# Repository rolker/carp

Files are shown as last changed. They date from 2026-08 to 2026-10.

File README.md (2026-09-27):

# CARP — Cheap-Ass ROV Project

A low-cost, ROS 2–capable inspection ROV for relocating and imaging sidescan
sonar contacts in shallow water, deployed from a kayak.

## Mission

CARP is a long-daydreamed ROV build with a concrete first job. Sidescan and
bathymetry surveys produce contacts faster than anyone can dive them; CARP is
a cheap camera platform for closing that loop: drop on a contact, find it,
image it, and log the result against the sonar record.

That job drives the v1 design but isn't the only goal — the envelope below
describes the first site, not the vehicle's ambitions. Deeper sites are
expected later (see ADR-001).

**Operating envelope**

| Parameter | Value |
|---|---|
| Design depth (v1, first site) | 5 m |
| Expected visibility | ~3 m |
| Working radius | ~15 m from downline |
| Deployment | Kayak, tethered |
| Water | Freshwater primary; saltwater capable |
| Cost | ~$2,000 as built (the "$500 build" did not survive contact with procurement — see `docs/bom.md`) |

## Design posture

Current leanings from an early design brainstorm, not final commitments —
`docs/decisions.md` grades each record by how committed it actually is.

- **Tethered, not autonomous.** The tether is not a limitation to be removed —
  it carries Ethernet, enables one-way acoustic ranging, and is the recovery
  path. See `docs/decisions.md` ADR-009.
- **Relocation is the hard problem, not the vehicle.** With 3 m visibility you
  can sit on top of a target and not see it. The downline is the primary
  navigation aid.
- **ArduSub for control, ROS 2 for payload.** Pixhawk owns the control loop;
  the Pi owns cameras, logging, and future DSP.
- **Project11 interfaces where they transfer**, not the full autonomy stack.
  See ADR-010.

## Repository layout

```
docs/
  decisions.md          Architecture decision records
  bom.md                Bill of materials, ordered vs pending
  power-budget.md       Load analysis, battery sizing, wiring gauge
  wiring.md             Power tree, signal map, grounding rules
  frame-and-mixing.md   ArduSub motor matrices, verified from source
  housing-layout.md     Tube diameter, dome fit, endcaps, frame geometry, CAD variables
  sled.md               Camera mount, slide-out sled, stereo test plan
  bringup-checklist.md  Bench acceptance tests before anything is sealed
  field-checklist.md    Dive-day card: night-before, launch, in-water, after
  navigation.md         Downline method, scaling lasers, acoustic ranging
  open-questions.md     Unresolved decisions
  prior-art.md          Survey of other cheap ROV builds, distilled lessons
params/
  ArduSub parameter files
```

## Status

Pre-build. Everything ordered has arrived (inventoried 2026-09-26) — Phase 1/2
acceptance testing still to do. The topside dry box came too small and needs
replacing.
Mechanical design open. Print shop online as of 2026-08-30 (Onshape →
Centauri Carbon 2, validated on a Pi 5 bench holder).

## License

TBD

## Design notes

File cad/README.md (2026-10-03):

# CAD

> **Decided vs proposed:** most of this file is agent proposals from design
> discussion, not approved decisions. `docs/open-questions.md` lists which
> is which — check it before treating anything here as settled.

Onshape is the CAD tool; the Centauri Carbon 2 prints the parts. This file
is the working plan for turning `docs/sled.md` and `docs/housing-layout.md`
into a printable stereo camera carrier. Trim it as the steps get done.

- `vendor/` — manufacturer STEP files (git-ignored) and where to get them
- `reference/` — vendor drawings (Pi 5 mechanical)
- `prints/` — STLs of parts actually printed, so a print traces back to a design
  (`pi_bracket.stl`: the 2026-08-30 Pi 5 bench holder, Onshape practice part,
  in daily bench use. Its two pins beside the corner pins, at (3.5, 9.5) and
  (61.5, 46.5), sit in the Pi 5's **Active Cooler mounting holes** — cut them
  off or reprint without them before fitting the cooler, and keep the space
  under those holes clear for the cooler's push-pin tips;
  `coupon_a_c1.stl` and `coupon_b1.stl`: the 2026-09-28 tolerance
  coupons, §4)
- `onshape-notes.md` — Onshape plans, API limits, AI/MCP options and 2026
  changes, for agents (researched 2026-09-27)

**Onshape document:** `carp` (folder `carp`) —
<https://cad.onshape.com/documents/ec758b3ca6b65519093ac0d1>

## Next bench print: Pi holder + stereo bar in one piece

The Pi holder has to be reprinted without the cooler-hole pins anyway, so
the next iteration combines it with a stereo camera bar (both cameras at
`stereo_baseline` on standoffs, stock 150 mm cables to the Pi) as one bench
print — the stage-1 air test rig.

- **Use an Assembly to check fit, a Part Studio to make the print.** An
  assembly exported to STL is several overlapping solids again. For one
  printed piece, bring the holder into the camera bar's Part Studio with a
  *Derived* feature (or rebuild it there) and join them with *Boolean →
  Union*, so the export is a single solid.
- Drop the two cooler-hole pins; keep the four corner pins.
- **Print-only camera seats: slide-in rails** (`docs/sled.md`, "Holding each
  board"), chosen 2026-10-02 from the coupons (§4). Groove height from
  coupon A.

## First target: camera carrier + stand-in plate

Not the sled yet. The first print is **stage 1 of the test plan in
`docs/sled.md`**: the camera carrier and a printed stand-in for the front
lid. Small, needs no housing, and it tests the part that matters most.
Model it so it grows into the real front lid and sled without a restart.

## 1. Measure first

Calipers, ~20 minutes. These decide the geometry. Fill in the values here,
then carry them into the docs (the way the 71.9 flange went into
`housing-layout.md`).

| Measurement | Value (mm) | Notes |
|---|---|---|
| Dome height `H`, flange back face → apex | 26.7 ± 0.2 | Straightedge bridged across both domes (2026-09-27): rule on edge 46.1 − 19.6 = 26.5; rule flat 27.6 − 0.7 = 26.9 |
| Dome glass OD `2R` | 52.4 | Taken 1 mm above the flange front face (2026-09-27); glass narrows right away, no cylindrical skirt |
| Dome glass ID at the flange | 47.25 | Measured 2026-09-27 from the back. Wall (52.4 − 47.25) / 2 ≈ 2.6 |
| Dome flange thickness | 2.0 | Measured 2026-09-27. The listed 3/8" flange is the radial width: (71.9 − 52.4) / 2 = 9.75 |
| B0444 board width × height | 25.1 × 24.4 | Measured 2026-09-27. STEP says 25 × ~24 |
| B0444 hole pattern | 21.05 × 12.55, Ø≈2.0 | 2026-09-27, caliper spans (outer / inner): 21-dir 23.1 / 19.0 → 21.05, Ø 2.05; 12.5-dir 14.5 / 10.6 → 12.55, Ø 1.95. Matches STEP (21 × 12.5). Two earlier 12.5-dir readings (14.7 / 11.55, 14.55 / 11.5) gave ~13.1 but an impossible Ø ~1.55 — bad inner span, discarded. STEP lists Ø2.2 |
| B0444 lens front above board front face | 17.0 | 2026-09-27, at current focus: lens front → PCB back 18.7 − PCB 1.7. STEP says ~16; changes with focus |
| B0444 lens barrel OD | 14.0 | Measured 2026-09-27. STEP says ~14 |
| B0444 back-side component height | 2.2 | Measured 2026-09-27. STEP says ~2 |
| B0444 connector + ribbon stub past board edge | 8 (design) | 2026-09-27: 12.5 with a loose bend; can be bent to the STEP's ~8. Design to 8 and have the carrier hold the bend (clamp behind the connector) so the ribbon cannot pull on the latch |
| B0444 front-face edge clearance | ≥ 1 clear | 2026-10-02: nothing within 1 mm of the slid edges on the lens side — the rail lips (1.0 overlap) clear |
| B0444 connector height | 2.3 proud of the back face | 2026-10-02. On the back (opposite the lens); the tallest back-side part, so it sets the 2.2 → 2.3 clearance. Ribbon leaves parallel to the board, straight out past the edge |
| Stock camera cable reach | ~100 | 2026-10-02: usable distance from Pi 5 camera connector to board connector on the ~150 mm stock cables, allowing for the bends. Sets where the stereo bar sits relative to the Pi holder |
| Active Cooler push-pin tips below the Pi board | 3.5 | 2026-10-02, measured before fitting. The holder must leave this clear under the two cooler holes |

**Dome centre (from the rows above):** sagitta from the OD point (3.0 above
the flange back face): h = 26.7 − 3.0 = 23.7, r = 26.2, so
R = (h² + r²) / 2h = **26.3** — a hemisphere, to measuring accuracy. The
centre of curvature sits **H − R ≈ 0.4 in front of the flange back face**,
i.e. on the lid's outer face (plus any gasket under the flange). The 2 mm
flange cannot clip the 141° cone: the edge ray (70.5°) leaves the glass
~8.8 above the centre, well clear of the flange top at ~1.6.

- [x] **Sensor row direction:** photograph a horizontal edge with the
      connector down. Do the pixel rows run along the 25 mm side? Result:
      **yes** — rows run parallel to the connector edge (a 25 mm edge; the
      24.4 direction runs connector → far edge). Inferred, not photographed:
      cables-up boards gave upright 1920-wide landscape frames with no
      rotation or flips anywhere in the chain (orientation checks below).
      Connector-down is the same axes rotated 180°.

### Image orientation — which way up is upright?

The bench tests ran with the boards' printing upside down and the cables
up, and the images looked upright. Nothing in this repo rotates or flips
(launch file, patches, scripts checked 2026-09-27), so one of:

1. **The sensor is upright that way** — the board's natural orientation is
   connector-up.
2. **libcamera corrected it** — the overlay declares a `rotation`, and
   camera_ros's default orientation makes libcamera compensate using the
   sensor's own flip bits (no CPU cost, but it reverses the row readout
   order).
3. **The viewing step flipped it** — an ffmpeg/Python preview in the test
   session, not the bag itself.

Checks, on the Pi:

```bash
# 1. Does the overlay declare a rotation? (big-endian u32: 0 or 180)
xxd /proc/device-tree/axi/pcie@120000/rp1/i2c@88000/arducam_pivariety@c/rotation

# 2. With cameras.launch.py running: are the sensor flip bits set?
for d in /dev/v4l-subdev*; do echo $d; v4l2-ctl -d $d --list-ctrls | grep -i flip; done

# 3. Ground truth: cables up, camera pointed at a sheet with "TOP ↑" on it,
#    view a frame decoded straight from the bag in a stock viewer.
```

| Result | Meaning |
|---|---|
| No rotation property, flips off | 1 — cables-up is upright |
| Rotation 180, flips on | 2 — libcamera corrects for a connector-down board |
| Bag frame upside down | 3 — the preview was flipped after the fact |

- [x] Rotation property: **0** (both; `orientation` 2 = external) — Flip
      bits while streaming: **H 0, V 0** (both; camera_ros `orientation` 0)
      — Bag frame upright?: **yes** (2026-09-26 frames decoded with plain
      ffmpeg, and raw-Bayer previews written in sensor row order, both
      upright with the boards cables-up). **Result 1: cables-up is the
      sensor's natural upright.** A "TOP ↑" sheet shot would confirm
      directly.

**For the carrier:** any orientation works as long as both boards are
mounted the same way and both cameras run identical settings — that keeps
the readout order matched for the sync. Pick cables-up or cables-down for
ribbon routing to the Pi, then make the software match (camera_ros
`orientation`) rather than bending the mount to suit. **Calibrate with the
final orientation settings** — changing them afterwards invalidates the
intrinsics. Update the "connector down" assumption above, and `sled.md`,
once decided.

## 2. Onshape document structure

One document, `CARP`:

| Tab | Contents |
|---|---|
| **Variable Studio** `Housing` | Driving variables (list below) |
| **Part Studio** `B0444` | Imported STEP from `vendor/` |
| **Part Studio** `Dome` | Simple model from the measurements: 2.0 flange disc + R 26.3 hemisphere, centre ~0.4 in front of the flange back face, marked as a mate connector |
| **Part Studio** `Front` | Multi-part: layout sketch, lid, carrier, spacers, stand-in plate |
| **Assembly** `Front check` | Two cameras + two domes placed on the parts; clearances and axis alignment |

**`Front` is one multi-part Part Studio** — the Onshape idiom for parts
designed around each other. Lid, carrier and stand-in all reference one
layout sketch, so changing `stereo_baseline` moves everything together, and the
drilling jig comes later from the same sketch.

**Coordinates:** origin at the **front pipe end, on the tube axis** (= the front
lid's inner face; `housing-layout.md`, "Coordinate frame"), +X
forward along the optical axes (vehicle X), **Y to port**, Z up —
right-handed, ROS REP-103, same as `housing-layout.md`, so this drops into a
vehicle assembly (and a URDF export) later.

### Variable naming conventions

Settled 2026-09-27, before the Variable Studio existed — renaming later does
not update expressions that already use a name.

1. **snake_case, whole words, subject first:** `dome_flange_diameter`, not
   `flangeOD`. Names group by part (`camera_*`, `dome_*`, `lid_*`, `tube_*`)
   and match the ROS side of the repo.
2. **Property words:** `diameter`, `radius`, `thickness`, `width`, `height`,
   `length`, `depth`, `spacing` (centre to centre), `offset`, `gap`,
   `clearance`. The only abbreviations are `min` and `max` (and `cg`).
   Say what is meant: `camera_hole_spacing_x`, not `camera_hole_x`.
3. **Axes as a final `_x` / `_y` / `_z`** — vehicle frame (X forward, Y port, Z up)
   unless it is plainly a board's own axes.
4. **Derived values are expressions,** not typed numbers:
   `tube_inner_diameter = tube_outer_diameter - 2 * tube_wall_thickness`.
5. **Units always** (`74 mm`), and the **source in the description field**
   ("measured 2026-09-27", "design choice, sled.md", "from coupon").
6. **Shared vs local:** anything used by more than one Part Studio, or named
   in the docs, lives in the `Housing` Variable Studio. One-part dimensions
   (a rib thickness) are local Variable features. A local variable never
   reuses a shared name.
7. **Print fits get their own variables** so coupon results feed straight
   in (e.g. a rail groove width, a pin diameter), separate from the
   measured dimension they fit (`camera_board_thickness`).
8. **This table mirrors the Variable Studio.** Change a value in Onshape →
   update the table in the same commit as the print or measurement.

### Variable Studio contents

| Variable | Value | Source |
|---|---|---|
| `tube_outer_diameter` | 168.3 mm | 6" sched-40 |
| `tube_wall_thickness` | 7.11 mm | 6" sched-40 |
| `tube_inner_diameter` | `tube_outer_diameter - 2 * tube_wall_thickness` → 154.1 mm | Derived |
| `seal_diameter` | `(tube_outer_diameter + tube_inner_diameter) / 2` → 161.2 mm | Derived; O-ring centreline |
| `stereo_baseline` | 74 mm | Minimum; 74–~95 allowed (`sled.md`) — **decision open** |
| `dome_flange_diameter` | 71.9 mm | Measured 2026-09-26 |
| `dome_bolt_circle_diameter` | 64.5 mm | Measured 2026-09-26, 6 holes ~Ø2.0 |
| `dome_flange_gap_min` | 2 mm | Rule: flanges don't touch |
| `lid_thickness` | 19.05 mm | 3/4" acrylic; 9.53 for the aluminium option |
| `lid_width` | 203.2 mm | 8" |
| `tie_rod_circle_diameter` | 184 mm | M6 tie rods at 45° |
| `camera_hole_spacing_x` | 21 mm | B0444 hole pattern, along the board width (measured 21.05) |
| `camera_hole_spacing_y` | 12.5 mm | B0444 hole pattern, along the board height (measured 12.55) |
| `camera_axis_offset` | 1.3 mm | Hole-pattern centre to optical axis, toward the connector |
| `camera_board_width` | 25.1 mm | Measured |
| `camera_board_height` | 24.4 mm | Measured |
| `camera_lens_height` | 17 mm | Board front face to lens front, measured at current focus |
| `camera_hole_diameter` | 2.0 mm | Measured (STEP 2.2) |
| `camera_board_thickness` | 1.7 mm | Measured 2026-09-27 |
| `camera_lens_barrel_diameter` | 14 mm | Measured; retainer holes clear it |
| `camera_back_component_height` | 2.2 mm | Measured; standoffs clear it |
| `camera_connector_reach` | 8 mm | Connector + tightly bent ribbon past the board edge |
| `dome_height` | 26.7 mm | Flange back face → apex, measured 2026-09-27 |
| `dome_radius` | 26.2 mm | Glass OD 52.4 / 2; sagitta gives 26.3 — hemisphere |
| `dome_flange_thickness` | 2.0 mm | Measured |
| `lid_hole_diameter` | 17 mm | Through-hole for the Ø14 barrel; 16–18 |
| `lid_counterbore_diameter` | 52 mm | Counterbore from the inside for board + connector |
| `lid_counterbore_depth` | 8 mm | Board needs 4.5–7.5; rest is tune margin |
| `tube_length` | 400 mm | **Provisional** — bay stack total, `housing-layout.md` |
| `camera_pupil_depth` | 3 mm | Lens front → entrance pupil. **Estimate**; the wet tune corrects it |
| `dome_center_x` | `lid_thickness + dome_height - dome_radius` → ~19.5 mm | Derived: dome centre (and the camera pupils) in front of the origin |
| `sled_tray_top_z` | −55 mm | Tray top below the axis; ≥ −58.6 so the 100-wide pack pair fits the bore |
| `camera_spacer_thickness` | 3 mm | Starting guess; set per camera by the wet tune |
| `camera_standoff_height` | 3 mm | Board standoffs; clear the 2.2 back-side parts |
| `camera_pin_diameter` | 1.8 mm (placeholder) | *If* printed pins win: pin diameter for the Ø2.0 board holes — set from the coupon (1.8 / 1.85 / 1.9) |
| `print_fit_clearance` | 0.2 mm (placeholder) | General sliding-fit allowance per side — set from the coupon |

## 3. Build order inside `Front`

1. **Layout sketch** on the lid's outer-face plane:
   - the two optical axes at ±`stereo_baseline`/2
   - the dome flange circles and their six-hole patterns
   - the pipe bore and pilot-ring circle
   - the tie-rod circle

   Add a constraint that makes the model fail when the flanges collide
   (`dome_flange_gap ≥ 2`).
2. **Lid** at `lid_thickness`, modelled but not printed — the reference the carrier
   mounts to, and later the drawing for the acrylic.
3. **Camera carrier:**
   - two board seats, each hole pattern 1.3 off its axis toward the
     connector
   - **both boards the same way up** — never mirrored (rolling-shutter
     readout has to match for the sync, `sled.md`)
   - ribs across the span between them
   - board seats per the chosen print-only method (`docs/sled.md`)
   - dowel + screw interface on its front face (to the lid)
   - a slot for each ribbon to exit rearward
4. **Spacer** — one part with an Onshape **configuration** table for
   thickness, 2.5 to 6 in 0.5 steps. Export the set as STLs.
5. **Stand-in plate** — just the lid's inner-face interface (dowel and screw
   holes) plus feet to stand on the bench. It doesn't need to be 19 thick
   or 8" square; only the region the carrier bolts to.

## 4. Printing

- **PLA+ for stage 1** — it is bench only (`docs/bom.md` material rule).
  Reprint in PETG before it goes in the vehicle.
- **Print a tolerance coupon first** — cheaper than reprinting the
  carrier; it picks the board-seat method. Modelled 2026-09-28 in two Part
  Studios (layout proposed by an agent, sizes are starting guesses):
  - **`Coupon A`** (PLA+, one part, 110 × 60 × 8.5, plate down, no
    supports; label "C1"):
    - three **rail pairs**: walls 3 wide × 6.5 tall, lips 23.1 apart
      (`camera_board_width - 2 * coupon_lip_width`), grooves 25.4 wide
      (`camera_board_width + 0.3`) with the floor at
      `camera_standoff_height`, groove height 1.7 + 0.1 / 0.2 / 0.3; end
      stop at the back, board slides in connector end last
    - three **pin pads**: Ø4 bosses × 3 on one diagonal of the 21 × 12.5
      hole pattern, pins Ø1.80 / 1.85 / 1.90 × 2.2 (0.5 above a seated
      board)
    - embossed labels 0.4 high
  - **`Coupon B`** (PETG, nine parts, 112 × 35 × 15, no supports,
    0.12 layers for the threads):
    - two **latches**, printed flat so the arm flexes in the bed plane:
      arm 1.0 / 1.4 × 12, hook 0.8 over a 3 ramp, channel 8.2, rigid wall
      2.5; one **catch** block 8 × 8.8 fits both (0.6 arm deflection)
    - three **M6 × 1.0 stud + nut pairs** (Plastic Thread, ISO profile,
      presets Close / Normal / Loose, labelled C / N / L): studs Ø6 × 12
      on 12 × 12 × 3 bases, nuts 10 A/F × 5
  - **Results** (fill in after printing):

    | Test | Result |
    |---|---|
    | Rails +0.1 / +0.2 / +0.3 | 2026-09-28: +0.1 a bit too tight, +0.2 a bit loose. 2026-10-02: +0.1 works well after a few insertions — **use +0.1** |
    | Pins 1.80 / 1.85 / 1.90 | 2026-09-28: all too small, board moves around. 2026-10-02: pins measure ~0.05 under design (1.90 → ~1.85) |
    | Latch 1.0 / 1.4 (20 cycles) | 2026-10-02: both snap in and work, but hold weakly; 1.0 is weaker |
    | Nut C / N / L | 2026-10-02: all thread smoothly, all wobble a little (L most, C least); all hold when snug |
- **Carrier printed seat-side up** (rails stand up from the seat face, as on
  coupon A). Both seats finish on the same top layer, so they come out flat
  and coplanar. 4+ walls, ≥ 40% infill.
- **Hardware not yet bought** (not in `docs/bom.md`):
  - Nothing for the board seats — print-only (M2 × 6–8 screws + inserts
    only as a fallback)
  - M3 or M4 inserts + screws (carrier to plate)
  - 3 mm steel dowel pins
  - a heat-set tip for the soldering iron

## 5. Tying it back to the repo

- Put the Onshape document link at the top of this file, and name Onshape
  versions to match git commits (e.g. "carrier v1 — 8b89fd0") when a part
  is printed.
- Export STLs for parts that were actually printed, so a print traces back
  to a design.
- Measurements go into the docs once taken.

## First test

Cameras on the carrier, stock 150 mm cables to the bench Pi, calibrate in
air with ROS `camera_calibration` in stereo mode. Check:

- the calibrated baseline matches `stereo_baseline`;
- rectified images line up row for row.

Both hold → the carrier is rigid and correctly oriented. A baseline that
drifts between calibration runs means the print is flexing.

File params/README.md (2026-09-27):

# ArduSub Parameters

Parameter files for CARP, one per configuration stage.

## Conventions

- Export from QGroundControl after each verified change
- Commit the *whole* file, not diffs — ArduSub params are order-independent and
  the full snapshot is what gets reflashed
- Name files `carp-<stage>-<date>.params`

## Known non-default values

| Parameter | Value | Why |
|---|---|---|
| `BRD_SAFETY_DEFLT` (was `BRD_SAFETYENABLE` before 4.7) | 0 | No physical switch reachable in a sealed housing (ADR-007) |
| `BARO_EXT_BUS` | *(set to external bus index)* | Defaults to −1 (disabled). Most common cause of "depth sensor not detected" |
| `FRAME_CONFIG` | *(pending frame decision)* | ADR-012 is Open — six thrusters make BlueROV1 a live alternative to SimpleROV-4/5 |
| `LEAK1_PIN` / `FS_LEAK` | *(AUX pin)* / surface | Leak probe auto-surface failsafe (design review M8) |
| `BATT_VOLT_MULT` | *(calibrate)* | Radiolink power modules are known to read low |
| `MOT_n_DIRECTION` | *(as needed)* | Correct thruster rotation here rather than rewiring inside the housing |
| `MAV_GCS_SYSID` (was `SYSID_MYGCS` before 4.7) | 255 | Required for QGC/Cockpit joystick authority; the #1 "no control" cause |
| `SERIAL2_PROTOCOL` / `SERIAL2_BAUD` | 2 / 921 | Only if Pi connects via TELEM2 UART instead of USB |
| `FS_PILOT_INPUT` | *(verify)* | Pilot-input failsafe timing — matters with browser-based control (Cockpit tab focus) |

**Firmware target:** `Pixhawk1-1M` from Sub/stable (genuine FMUv2 is 1 MB;
plain `Pixhawk1` assumes 2 MB and fails to flash). Pin the working `.apj`.
**Flashed and working (2026-09-26): ArduSub 4.7.1, git `dbe79216`**, loaded
as a custom firmware file from QGC 5.1.4 on Windows. **This board has
2 MB of flash** — the 1M build logs `2M flash - use Pixhawk1 firmware` on
every boot — so it now runs the **full `Pixhawk1` build**, same 4.7.1 /
`dbe79216`, reflashed 2026-09-26 (ADR-008). Pin *that* `.apj`:
`firmware.ardupilot.org/Sub/stable/Pixhawk1/ardusub.apj`.
Custom control code note: MAVLink MANUAL_CONTROL z-axis neutral is **500**
(0–1000 scale), unlike x/y/r at ±1000 — z=0 means full descent on arm.

## Not available

`SUB_FRAME_CUSTOM` is an empty case in `AP_Motors6DOF.cpp`. There is no
parameter-driven custom motor matrix — a custom frame requires a firmware fork.

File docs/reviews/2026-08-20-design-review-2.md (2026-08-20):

# CARP Design Review — 2026-08-20 (second pass)

Independent review by a second agent. The first review (`2026-08-20-design-review.md`)
is excellent and most of its findings have already been incorporated into the source docs.
This pass checks whether anything was missed or left unacted-on, and adds new observations.

Findings ranked BLOCKER / MAJOR / MINOR.

---

## What the first review got right that remains solid

The core architecture (ArduSub + Pi over USB/MAVLink), buoyancy math, wiring gauge
analysis, vacuum gate corrected to 15 inHg, acoustic ranging math and
tether-as-sync-path argument, snag protocol rewrite, and the decision to stay tethered
are all sound. `frame-and-mixing.md`, `sidescan-datum.md`, and `prior-art.md` remain
correct as written.

---

## First-review findings that are still open (not yet acted on)

### B2 carry-forward — snag protocol not in the checklist
ADR-009 now has the correct rewrite. `bringup-checklist.md` Phase 5 has no snag drill
or "haul-test from multiple bearings" step. A written procedure that is never practiced
is not a procedure.

### M3 carry-forward — external compass not on any BOM line
The first review calls for a ~$15–30 external I2C compass and MagFit in Phase 3/5.
Neither the BOM pending section nor the bringup checklist has been updated. It will
surface on first water, not in a drawer.

### M4 carry-forward — ADR-017 not written
The first review calls for ADR-017 (Pi software stack decision) before Phase 3. It is
not in `open-questions.md`, not in `decisions.md`, and not in any checklist. It will
get skipped unless explicitly tracked.

### Minor 10 carry-forward — thermal soak duration discrepancy
The first review recommended 45 min sealed soak; `bringup-checklist.md` Phase 3 says
30 min. One of them is wrong.

### Minor 12 carry-forward — no field-day ops checklist
`bringup-checklist.md` covers bench phases only. First dive needs its own card: cell
voltages, vacuum hold check, tether flaked, quick-release confirmed, downline dropped
and clipped, disarm before hands near props. This was flagged and not created.

---

## MAJOR

### MA1. Relief path in the endcap is called for but never specified

ADR-013, `power-budget.md`, and the bringup checklist all say "relief path in
endcap — confirmed." No doc says what it is: a Schrader valve? A burst disk? A
pop-off rated to what pressure? Without a specific part and a test procedure, this is
a checkbox with no method. A swollen 4S pouch in a sealed PVC tube with a vague
"relief path" is still an unresolved hazard.

**Fix (~$5):** one Schrader valve stem in an endcap hole, core in during diving (seals
against water), core removable for bench venting. Same part already called for by the
vacuum test (it is already in the BOM pending section as "Schrader valve stem + core
tool" — confirm it serves both roles and cross-reference in ADR-013).

### MA2. Camera pod / housing layout is the most blocking unresolved mechanical question

The 2" dome cameras are ordered. Camera pods are "a candidate" in `open-questions.md`.
CSI ribbons are not wet-rated and cannot pass a gland — correctly flagged in the first
review (M5) — but no fallback is specified. The main housing endcap cannot carry two
~70 mm flanges on a 4" cap. There is no pod design, no housing diameter decision, and
no frame layout. These three questions are the same problem and must be resolved before
pipe is purchased.

**Fix ($0):** add "lay out camera geometry and housing diameter on paper before buying
any pipe" as a Phase 0 item, immediately after the battery dimensions are measured on
arrival.

### MA3. XT90-S anti-spark resistor is a consumable — not mentioned anywhere

The pre-charge resistor in the XT90-S male pin is rated for a finite number of
insertions (typically 30–50) before it degrades and the connector becomes a plain XT90.
Field operations mean connecting and disconnecting every dive. There is no mention of
inspecting or replacing the anti-spark element, and the XT90-S is currently the only
inrush protection. When it fails silently, every subsequent connect is a hard spark
into a 6 Ah pack through a 10 AWG lead inside a sealed tube.

**Fix (~$8):** add "inspect XT90-S male pin for contact pitting every N dives; carry
a spare male XT90-S in the field box" to the field ops checklist. Document the wear
limit.

---

## MINOR

1. **Tether working-radius math is never closed.** `navigation.md` assumes "15 m from
   downline." If the tether routes boat → downline clip → ROV, the effective horizontal
   radius is tether length minus downline vertical depth (~5 m), leaving ~10 m. Draw
   the rigging geometry explicitly.

2. **Pololu D36V50F5 margin is thin and not documented as accepted risk.** 25 W peak
   Pi load = 91% of the 27.5 W converter rating, in a sealed tube with no active
   cooling. USB audio + NVMe tighten this further. Either document the accepted risk or
   replace with a 6–8 A part.

3. **Actual tether link speed on CCA Cat6 is never verified.** The offload plan
   (ADR-016, "100 GB in 20 min") needs 1000BASE-T. CCA Cat6 at this length may or may
   not negotiate gigabit — some runs degrade to 100 Mbps or worse. Test once on the
   actual tether/Opal combination and record it before the storage architecture hardens.

4. **No bandwidth budget for two RTSP streams + MAVLink + ROS topics on one 100 Mbps
   link.** Two 1080p streams at moderate bitrate are 8–16 Mbps; `udp_bridge` topic
   volume is unknown. This probably fits, but nobody has added it up.

5. **2" acrylic domes have no spares.** $10.69 each, "handle gently." A cracked dome
   mid-season ends the mission. One spare is cheap insurance — especially since they
   are described as having already been ordered through a single third-party seller.

6. **Tether attachment: navigation.md says clip to downline; bom.md says to the
   boat.** The first review flagged this (Minor 3) as "probably compatible — draw the
   rigging." It has not been drawn. The rigging diagram resolves this and the working-
   radius question simultaneously.

7. **8BitDo + Cockpit over WiFi: no range/link-reliability test planned.** The Opal's
   5 GHz AP has ~20–30 m open-air range. Water spray and a metal kayak hull can
   degrade this. The backup control path if WiFi drops is the tether; acceptable, but
   worth a bench qualification (router in the dry box, phone at operating distance,
   confirm no dropout under motion).

---

## Sequencing additions

Two Phase 0 items deserve promotion from "before Phase 3":

1. **Camera geometry + housing layout** — before pipe purchase, which is earlier than
   Phase 3.
2. **ADR-017 (Pi software stack)** — before *any* software integration work in Phase 3.

And one Phase 5 addition: **snag drill** — gentle haul-test from multiple bearings,
confirm the protocol works with the actual rigging before the first unsupervised dive.

---

## Top 5 priorities from this pass

1. Specify the LiPo relief path (name the part, cross-reference the Schrader stem
   already in the BOM) — closes MA1 in one sentence in ADR-013.
2. Add camera geometry / housing layout session as Phase 0 item — closes MA2.
3. Add XT90-S wear note and inspection step to field ops checklist — closes MA3.
4. Write ADR-017 and add the external compass to BOM pending — closes M3 and M4
   carry-forwards from the first review.
5. Write the field-day ops checklist — closes the Minor 12 carry-forward.

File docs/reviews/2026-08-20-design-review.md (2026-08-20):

# CARP Design Review — 2026-08-20

Independent review by a fresh agent with no conversation context; read the
full repo and re-derived the math. Findings ranked BLOCKER / MAJOR / MINOR.

---

## BLOCKER

### B1. No overcurrent protection anywhere in the electrical system
`wiring.md` power tree, `power-budget.md`, and `bom.md` contain no fuse,
breaker, or current limit of any kind. The system is a 6 Ah pack the docs
themselves credit with **>=120 A** delivery, feeding 10 AWG through a sealed
tube that explicitly "cannot be inspected mid-dive." A chafed 14 AWG ESC drop
or a swollen pouch shorting against the frame is an unfused dead short in a
closed PVC vessel next to a LiPo. The XT90-S anti-spark is inrush management,
not protection.

**Fix (~$15):** one MIDI/ANL 80 A fuse on the pack lead at the star point,
plus optionally 15 A blade fuses per ESC drop. Add "main fuse installed and
verified" to Phase 3.

### B2. Solo free-diving to clear tether snags is the plan of record
ADR-001 and ADR-009 both treat "at 5 m you can free-dive to clear a snag" as
the tether-fouling answer. This is solo breath-hold diving, from a kayak,
into your own entanglement hazard — the line that is snagged is the line that
snags *you*. This is how experienced watermen die.

**Fix ($0):** rewrite as haul-test -> slack-and-reposition -> abandon and
return with a buddy or a grapple. Free-diving on a fouled line is a
two-person operation, full stop. The vehicle is ~$1,600; write that down.

---

## MAJOR

### M1. The all-in cost projection contradicts its own ledger
The BOM concludes "$1,550–1,700 all-in" but records $1,583.58 already paid
plus $325–445 of pending estimates. Floor: ~$1,909; with the file's own ~25%
overrun pattern on pending items: ~$1,990–2,100. The summary mixes ordered
*estimates* with pending estimates even though Paid is known and $438 higher.
The "$500 build?" answer is ~4x, not ~3x.

### M2. Battery-swap-per-dive is unreconciled with a sealed housing
ADR-013's rationale is swap between dives, but the housing doctrine demands a
vacuum re-test after every reopening — a field procedure written nowhere. The
housing open question never mentions the swap requirement, which is arguably
the strongest driver of closure design (tool-free field-serviceable face
seal) or of a separate battery tube (the OpenROV pattern prior-art already
endorses — which also solves relief venting and flood isolation in one move).

### M3. No workable heading source, and the mission depends on heading
The spiral search is dead reckoning on heading, but the only magnetometer is
inside the Pixhawk, inside a tube with six ESCs, the star point, and up-to-
56 A conductors. There is nowhere "away from ESC wiring" inside that tube. No
external compass exists in the BOM. Expect tens of degrees of throttle-
correlated heading error — a spiral that isn't a spiral.

**Fix (~$15–30):** external I2C compass on a mast/far frame corner in its own
potted blob; add "compass interference check under full thrust (MagFit)" to
Phase 3/5.

### M4. What runs on the Pi is undecided, and two docs assume different answers
README/ADR-010 assume ROS 2 + Project11; prior-art plans in detail around
BlueOS + Cockpit. No doc states whether the Pi runs BlueOS, vanilla OS +
mavlink-router + self-hosted Cockpit + ROS 2, or both containerized. This
decides the video pipeline, the control path, and half of Phase 3.
**Fix:** write ADR-017, one page, before Phase 3.

### M5. The dual-CSI purchase reintroduces the CPU problem ADR-015 was
written to avoid — and the pod idea has an unexamined wet-CSI problem
Two software-encoded streams are back on the Pi, plus recording, plus ROS.
Separately, the BOM says the 4" dome was "retired by camera pods," but pods
are only a *candidate* in open-questions, and CSI ribbons are not wet-rated,
can't pass a gland with connectors on, and are EMI-sensitive at ~20–50 cm.

**Fix ($0):** promote "prototype the CSI/encode pipeline at intended
resolution and ribbon length, measure CPU and watts" to a named checklist
item *before pipe purchase*.

### M6. Endurance numbers were never propagated after the lights were deleted
Per-pack runtime rows are still 150 W numbers (35/28 min); at the doc's own
post-ADR-004 ~110 W they are ~48/39 min. Phase 5 still says "against the
150 W estimate." One propagation pass needed.

### M7. Offload plan assumes gigabit; tether doctrine says 100 Mbps
ADR-016's "100 GB in under 20 minutes" needs 1000BASE-T, which prior-art
forbids counting on — and the ordered tether is CCA Cat6, the worst case. At
100 Mbps, 100 GB is ~2.2 h. Fix: offload overnight or via a short dockside
patch cable; test 1000BASE-T on the actual wet tether once and record it.

### M8. No leak detection failsafe — only passive logging
Internal-baro logging is post-dive forensics, not a response. ArduSub
natively supports leak probes (LEAK1_PIN, FS_LEAK=surface) on an AUX pin; a
probe is $5. Auto-surface-on-leak is the cheapest insurance in the project.
Expect condensate false alarms (mount and test accordingly).

---

## MINOR (abridged — see review conversation for full list)

1. Vacuum gate 10 inHg = 3.5 m < 5 m site depth. Pull 15 inHg (~5.2 m).
2. Tether identity drift: wiring says 20 m Cat5e; BOM ordered Cat6 cut ~15 m.
3. Tether attachment: navigation says clip to downline; BOM says to the boat.
   Probably compatible — draw the rigging.
4. BOM subtotal arithmetic drift between section headers and totals table.
5. README still advertises "~$500 core."
6. params/README lists FRAME_CONFIG=SimpleROV-4 but ADR-012 is now Open.
7. BOM asserts pods/dome-retirement that no ADR decided.
8. IMX462 IR-cut variant unconfirmed — add to arrival checks.
9. Phase 2 thruster runs: specify *in water*; 20 min dry is a warranty claim.
10. No sealed thermal soak: add 45-min sealed, everything encoding, SoC temp
    logged, before first water.
11. Desiccant on no BOM line.
12. No field-day ops checklist (pre-dive vacuum, cell voltages, disarm-
    before-hands-near-props — relevant since ADR-007 removed the switch).
13. Pololu ceiling: 25 W Pi-side peak = 5.0 A on a 5.5 A part in a warm
    tube; USB audio + NVMe land on this rail later.
14. Unsynced rolling-shutter stereo is not measurement-grade on a moving
    vehicle; lasers are the real instrument. Don't let the photogrammetry
    claim harden.
15. Acoustic ranging: the topside receive chain needs the same sub-100 us
    timebase — laptop wired to the Opal's LAN port, not WiFi. (The rest of
    the acoustics math checks out.)

## Sequencing

Phase order fundamentally sound. Three re-orderings: (1) the ADR-004 jar
test and bottom-texture check belong in Phase 0/1, the week the cameras
arrive — the whole no-lights architecture hangs on them; (2) CSI/encode
prototype before pipe purchase; (3) Phase 5 needs failsafe drills: kill
topside link mid-dive, pull power at depth, trip the leak probe.

Un-hedged SPOF: the Pixhawk itself — no spare, no fallback. The CCOM
"spare Pixhawks in a drawer" question is the free mitigation; ask early.

## Numbers checked and correct

Buoyancy math, pitch statics, sidescan error table, motor matrices vs
AP_Motors6DOF.cpp, raw-Image data rates, wire gauges vs currents, paid-total
addition, acoustics arithmetic. frame-and-mixing.md, sidescan-datum.md, and
prior-art.md are sound as written.

## What this plan gets right

Relocation correctly identified as the mission; genuine de-rating culture;
honest ADR commitment-grading with recorded reversals; vacuum-as-gate with
positive pressure demoted to debug; rejecting the custom-frame fork on a
flash-limited board.

## Top 5 priorities

1. Main fuse + leak failsafe (~$20 total) — closes both in-tube hazards.
2. Rewrite snag recovery to eliminate solo free-diving — a paragraph, today.
3. Prototype dual-CSI encode + decide the Pi software stack (ADR-017)
   before buying pipe.
4. Re-scope the housing question: field battery swap + external compass.
5. One numbers-propagation pass (cost, endurance, vacuum, tether, subtotals).

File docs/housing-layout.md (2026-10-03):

# Housing Layout and Frame Geometry

Resolves the coupled question `open-questions.md` calls "housing diameter and
camera mounting — one layout problem." Three unknowns (tube diameter, dome
spacing, endcap strategy) that only move together.

**Status: proposal.** Nothing bought, no pipe cut. ADR-012 stays open until
the measurements at the bottom of this file are taken.

## The options

| | Tube | Tube length | Envelope L×W×H | Verdict |
|---|---|---|---|---|
| **A** | 4" sched-40 | ~600–700 | ~750 × 350 × 250 | Cheap pipe, 2 extra penetrators, pods drift out of stereo cal |
| **B** | 6" sched-40 | ~400 | ~600 × 338 × 295 | **Leaning.** Domes on the front plate, one dry volume |
| **C** | 4" + oversized front plate | ~600–700 | ~750 × 350 × 250 | The seal is the hardest part on the vehicle and it is pressure boundary |
| **D** | 4" + mono camera | ~550–650 | ~700 × 350 × 250 | Cheapest path to water; drops stereo |

**Why B.** It resolves housing diameter, camera mounting, and whether pitch is
real, in one decision. Two secondary wins that have nothing to do with cameras:
the LiPos sit **side by side** in a 154 mm bore instead of stacked, and the six
ESCs **ring the tube wall** instead of eating axial length, so every one of them
gets a thermal path to the outside.

**What B costs.** ~$40–60 more in pipe and caps, more displacement so more lead,
more frontal area so more drag, and more dry weight over the gunwale — the
tradeoff `power-budget.md` names as "fine in water and awful at the launch."

## The fit — this is the whole argument

6" sched-40 is Ø168.3 OD, 7.11 wall, **154.1 bore**. Two 2" domes on ~Ø70
flanges:

| Centres | Flange span | Bore clearance | Gap between flanges |
|---|---|---|---|
| **75** | **145.0** | **+4.5** | **5** |
| 80 | 150.0 | +2.0 | 10 |
| 85 | 155.0 | −0.5 — does not fit | 15 |
| 100 | 170.0 | −8.0 — exceeds even the OD | 30 |

**The stereo baseline is not a free choice. The bore pins it at 75 mm** (74 once the flange was measured — see below). The
"~75–100 mm centres" carried in `open-questions.md` and the bring-up checklist
is really just 75. Anything wider forces an overhanging plate (option C) or 8"
pipe.

This costs nothing optically: 75 mm sits inside the 60–120 mm band
`prior-art.md` recommends for 0.5–2 m work.

At 75 mm the flanges land **inside the bore**, not merely inside the tube OD.
So the front plate is a plain disc sealing in the pipe — option C's
oversized-flange fabrication risk never appears.

> **Superseded by the endcap proposal below (2026-09-27).** A disc sealing
> *in* the pipe is a radial seal against the bore — the one prior-art.md says
> fails on out-of-round PVC. The proposal puts a flat lid *on* the pipe end
> instead, with the domes on its outside face, and that removes the reason the
> bore pinned the baseline: see `sled.md`, "The baseline is no longer
> pinned". The table and the 74 below still hold as the minimum.

### Measured flange: 71.9 — baseline moves to 74 mm

The table above assumed a ~Ø70 flange. Measured (2026-09-26) it is **71.9**:

| Centres | Flange span | Bore clearance | Gap between flanges |
|---|---|---|---|
| 73 | 144.9 | +4.6 | 1.1 |
| **74** | **145.9** | **+4.1** | **2.1** |
| 75 | 146.9 | +3.6 | 3.1 |
| 77 | 148.9 | +2.6 | 5.1 |

`bore_clearance >= 4` needs centres ≤ 74.2; the original `dome_flange_gap >= 5` needed
centres ≥ 76.9. No baseline satisfied both — until the bolt pattern was
measured.

**The bolt pattern retires the ≥ 5 gap rule.** Six holes, opposing pairs
spanning 66.5 outside / 62.5 inside: **Ø64.5 bolt circle, ~Ø2.0 holes** (M2
class — confirm with a screw). The bolts sit 3.7 mm in from the flange edge,
so they never reach the gap between flanges. Worst case, a hole on each flange
pointing straight at the other, the facing bolt centres are `stereo_baseline −
64.5` apart — 9.5 mm at 74, room for M2 heads and nuts. Clocked with holes at
±30° off the line between centres (free to do), that grows to ~18 mm. The gap
only needs to keep the flanges from touching, with print/placement tolerance:
**≥ 2**.

**Baseline: 74 mm.** It meets both rules (4.1 bore clearance, 2.1 gap) and
sits in the 60–120 band optically. 73 buys more bore clearance but leaves
~1 mm between flanges, too tight to place by hand.

## Frame — BlueROV1

Thruster numbering is ArduSub motor outputs, matching the matrix in
`frame-and-mixing.md`.

**Coordinate frame (CAD and ROS): X forward, Y to port, Z up** — right-handed,
ROS REP-103 body frame, and what Onshape builds in. Fixed 2026-09-27: earlier
revisions had port at −Y with Z up, a left-handed frame that would have
modelled mirrored.

**Origin: the front pipe end, on the tube axis** (= the front lid's inner
face). Moved 2026-09-27 from the tube's mid-length. Like a ship's aft
perpendicular and baseline, it is a physical datum fixed early that
everything mates to: the lid seats on it, the sled hangs from it, the tube
starts there. A lid-material change then moves only the lid's outer face and
the domes and cameras with it (optics unchanged); a tube-length change moves
only the rear. The tube runs from X = 0 to X = −`tube_length`. Z = 0 stays on
the tube axis, where `cg_z` and the BG target are already quoted from. The
dynamics frame — ArduPilot's, at the CG — is a fixed offset from this, set
after the float test. ArduPilot's own body frame (forward-right-down) is a
separate thing; the matrix factors in `frame-and-mixing.md` are in that
frame and are unaffected.

| Out | Role | Position |
|---|---|---|
| 1 | Horizontal port | Y +134, low, amidships-aft |
| 2 | Horizontal stbd | Y −134, low, amidships-aft |
| 3 | Vertical fwd-port | X −50, Y +134 |
| 4 | Vertical fwd-stbd | X −50, Y −134 |
| 5 | Vertical aft-centre | X −539, centreline |
| 6 | Lateral | X −459, **Z −30 — the CG datum**, aft of the rear cap |

Outputs 5 and 6 moved aft 19 mm when the rear cap became a 19 mm lid on the
pipe end — see "Endcaps". All X values are from the front pipe end (they
read +150 / −339 / −259 from the old mid-tube origin).

Verticals 3/4/5 form the triangle at **489 mm fore-aft separation** — better
than the 400 mm the pitch-authority calculation in `frame-and-mixing.md`
assumes, so that calc is conservative here. Outputs 3 and 1 share a side rail, as do 4 and 2, so each side is one
fabricated part carrying two thrusters.

## Notes

1. **Clock the flange bolt patterns.** Not strictly needed — the Ø64.5 bolt
   circle sits inside the flange, so facing bolts clear even when aligned —
   but rotating each flange so holes sit ±30° off the centre line doubles the
   spacing for free.
2. **All six thruster penetrators on the rear cap.** 18 phase conductors and
   two dome flanges cannot share one endcap. Front plate is domes only.
3. **Output 6 goes on the CG datum — hull-axis height, aft of the rear cap.**
   Not under the hull, and emphatically not above it. The BlueROV1 matrix
   carries a fixed −0.25 roll term for the couple a single off-CG strafe
   thruster induces, so the vertical offset is what makes that number right or
   wrong:

   | Position | Offset from CG | Couple at 1.7 kgf | vs righting moment @20° |
   |---|---|---|---|
   | Under the hull | −90 mm | 1.50 N·m | 1.9× |
   | Above the hull | +150 mm | 2.50 N·m | 3.1×, **and sign reversed** |
   | **CG datum** | **0 mm** | **~0** | **—** |

   Ballast is low, so CG sits ~30 mm below the hull axis: "up and over the top"
   is *further* from CG than under the hull, not nearer, and it flips the sign
   of the couple against a compensation term we cannot edit without forking
   ArduPilot. On the datum the couple vanishes and the sign question is moot.

   Two operational wins come free: no prop is the lowest thing on the vehicle,
   so hovering on a contact does not kick up silt into the shot, and there is
   less hanging down to snag.

4. **Route the tether over the top.** Output 6 now sits directly aft of the
   rear cap, where a tether led straight astern could be ingested. Exit high,
   strain-relieve to the frame, carry it up over the foam.
5. Foam high, ballast low, for the 2–3 cm BG the pitch-stability target wants.
6. **A long 4" tube is the wrong hull for BlueROV1.** Pitch inertia scales with
   length squared: a ~700 mm hull carries roughly 2–3× the pitch inertia of a
   ~400 mm one even after the fatter tube's extra mass. Choosing the six-
   thruster frame for camera aiming and then building option A means building
   the hull that makes aiming sluggish.

## Endcaps — proposal

**Status: proposal (2026-09-27).** Nothing bought. Replaces the "plain disc
sealing in the pipe" above.

**Both ends: a flat, square lid on the faced pipe end, held on by vacuum,
with tie rods as backup.**

- **Seal:** one O-ring lying on the pipe's end face (7.1 wide, centreline
  Ø161). Both pipe ends faced flat and square — wet-sand on 800 grit over
  glass, the Cave Pearl prep (prior-art.md). The lid face needs no prep;
  cast acrylic is cast between glass.
- **Clamp:** vacuum through the Schrader stem. 15 inHg on the Ø161 seal is
  **~1,040 N** at the surface; 5 m of water adds about as much again. The
  vacuum test that ADR-001 makes the gate is also the closure: pull 15 inHg,
  watch it hold, done.
- **Pilot ring**, printed, fixed to the lid's inner face (blind holes): drops
  into the bore to centre the lid, carries a clocking pin, and has a thin
  shoulder that backs the O-ring's inside edge (outside pressure pushes the
  O-ring inward, onto it) and acts as the compression stop. It is not
  pressure boundary, so FDM is fine. **Bench check:** does 15 inHg pull the
  lid down to the stop?
- **Tie rods:** four M6 on a **Ø184 circle at 45°**, outside the pipe (~5
  clear of the OD). That circle fits both an 8" square and an 8" disc (~7 of
  metal outside each hole), so the lid outline is free and one drilling jig
  serves acrylic squares and aluminium discs alike. Nuts set on fixed
  spacers ~1 mm off the lid — they keep a lid from leaving if the vacuum
  bleeds away in the kayak; they must never clamp, or they override the
  O-ring squeeze. Opening the front is: crack the Schrader, undo the four
  front nuts. The rear nuts stay put.
- **Relief for free:** a swelling pack or a hot Pi lifts the lid before the
  tube becomes a pressure vessel — the relief path ADR-013 and
  `power-budget.md` ask for. Crack the Schrader before opening, as ADR-013
  already says.
- **Leak monitor for free, probably:** the Pixhawk's onboard barometer reads
  hull pressure. Rising internal pressure during a dive is a leak, well
  before the SOS probes get wet. Unverified: confirm the Radiolink board has
  one and that ArduSub logs it.

**Front** is the service end: domes on its outside face, the sled on its
inside face (`sled.md`). **Rear** is hardly ever opened: penetrators, the
Schrader stem, and perhaps the ESCs as a heat path if the lid is aluminium.
A flat lid is a better penetrator face than a PVC cap's slight dome, and it
comes straight off without twisting cables — which rules out the threaded
cleanout plug, where every penetrator turns with the plug.

**Material: 3/4" cast acrylic, 8 × 8", both ends (~$40 each).** Clear, so the
O-ring contact, condensation and leak probes are visible. Aluminium only if
the sealed thermal soak says the Pi needs a heatsink — then **the front lid
only**, same outline and holes.

| Lid | Centre flex, 1 bar | Peak stress | Weight (air / net in water) | Cost |
|---|---|---|---|---|
| **3/4" cast acrylic** | ~0.13 mm | ~2.2 MPa (~7 at a hole; acrylic crazes ~10 sustained) | 0.93 / 0.15 kg | ~$40 per 8 × 8 |
| 1/4" 6061-T6 | ~0.16 mm | ~20 MPa (yield 276) | 0.71 / 0.45 kg | — |
| **3/8" 6061-T6** (front upgrade) | ~0.05 mm | ~9 MPa | 1.06 / 0.67 kg | SendCutSend, 2 × 8.5", 4 holes, anodised: ~$200 (quoted 2026-09-27, with 2-off discount) |

1 bar = surface vacuum plus 5 m. Simply-supported plate on the Ø161 seal —
rough; the two dome holes add maybe 1.5–2× to the front lid's flex.

- **Rejected on cost for v1:** the Blue Robotics 6" O-ring flange ($90 per
  end, plus a cap) epoxied into the bore — its radial O-rings are sized for
  BR's 151.9 ± 1.5 bore, not sched-40's 154.1. Revisit for v2.
- **Rejected:** HDPE (epoxy won't bond, so penetrator pots fail; creeps);
  single-layer 0.22" extruded acrylic (~13 MPa at the surface, cracks at
  holes); 6 × 6 sheet (smaller than the 154.1 bore).
- **Cheaper aluminium route:** Online Metals 8" discs (~$60 each; confirm
  it is 3/8" 6061), or a custom-cut 8 × 8 of 3/8" 6061-T651, drilled with the
  same jig as the acrylic. The jig locates from its own first hole (drill,
  pin, drill the rest), not the outline; steel or brass bushings in the
  printed body; flips on plugs in the Ø52 camera counterbores for the inner-face holes.
- **If 3/8" aluminium:** 6061-T6 (5052 only if salt water becomes routine),
  check flatness with a straightedge (< 0.1 across the seal; MIC-6 if not),
  anodise and use Tef-Gel on stainless threads. The re-quote should carry
  the whole front hole layout — the dome centres at `stereo_baseline` are the
  holes worth paying for, not the corners.

**Before ordering:** pick the O-ring (AS568 2-series, 0.139" cord, ID about
6.2" to sit mid-face) and check the corner rods and nuts against thrusters 1,
2 and 6.

## Onshape driving variables

Build the sketch on these, not on typed-in numbers. Assumed values are flagged
— every dimension in this document follows from the five of them.

| Variable | mm | Source |
|---|---|---|
| `tube_outer_diameter` | 168.3 | 6" sched-40 |
| `tube_wall_thickness` | 7.11 | 6" sched-40 |
| `tube_inner_diameter` | 154.1 | `tube_outer_diameter - 2*tube_wall_thickness` |
| `tube_length` | 400 | derived, see bay stack |
| `dome_flange_diameter` | 71.9 | **Measured 2026-09-26** (calipers) — over the 70 assumed, see below |
| `dome_glass_diameter` | 52.4 | **Measured 2026-09-27** — hemisphere R 26.3, flange 2.0 thick (`sled.md`) |
| `stereo_baseline` | 74 | set by bore + measured flange, see "Measured flange" — **74 is now the minimum, ~95 the maximum** (`sled.md`) |
| `lid_thickness` | 19.05 | 3/4" cast acrylic; 9.53 if the front goes to 3/8" aluminium |
| `lid_width` | 203.2 | 8" square (acrylic) or 8" disc (aluminium) — outline is free |
| `tie_rod_circle_diameter` | 184 | tie rods at 45°; fits both outlines |
| `seal_diameter` | 161.2 | O-ring centreline, mid pipe-end face: `(tube_outer_diameter + tube_inner_diameter)/2` |
| `dome_bolt_circle_diameter` | 64.5 | **Measured 2026-09-26** — 6 holes, ~Ø2.0 |
| `thruster_diameter` | 70 | **Measured 2026-10-02** — matches the assumption, nothing moves |
| `thruster_length` | 96 | **Measured 2026-10-02** (was 130 assumed) |
| `esc_length/width/height` | 75/30/15 | **ASSUMED — measure.** The U2 cable carries a sealed Ø20 × 72 cylinder 150 mm from the thruster, then > 1 m to a blue waterproof circular plug (2026-10-02 photo). The plug has **3 pins** (~5 mm spacing, ~10 long; shell OD 15, ID 11.5) — no separate ESC came in the box, so the cylinder is most likely a potted ESC outside the hull, and the 3 pins are V+, GND and signal. **Unconfirmed** — check with an ohmmeter across the pins (~0.1–1 Ω on all pairs would mean motor phases instead) |
| `pack_length/width/height` | 155/50/37 | `power-budget.md` |
| `rail_clearance` | 15 | chosen |
| `vertical_thruster_spacing` | 489 | driven by the tail arrangement |
| `cg_z` | −30 | ≈ BG below hull axis; **verify by float test** |

**Driven, not typed:**

```
rail_y                    = tube_outer_diameter/2 + thruster_diameter/2 + rail_clearance    -> 134
frame_width               = 2*(rail_y + thruster_diameter/2)                                 -> 338
thruster_6_z              = cg_z                                                             -> -30
thruster_3_x              = -50  (chosen: front verticals, 50 behind the front pipe end)      -> -50
thruster_6_x              = -(tube_length + lid_thickness + thruster_diameter/2 + 5)         -> -459
thruster_5_x              = thruster_6_x - thruster_diameter - 10                            -> -539
vertical_thruster_spacing = thruster_3_x - thruster_5_x                                      -> 489
dome_half_span            = stereo_baseline/2 + dome_flange_diameter/2                       -> 72.95
bore_clearance            = tube_inner_diameter/2 - dome_half_span                           -> 4.1
dome_flange_gap           = stereo_baseline - dome_flange_diameter                           -> 2.1
```

**Two inequalities are the design rules.** Make them sketch constraints so the
model breaks loudly rather than quietly:

```
bore_clearance  >= 4       (front plate seals inside the pipe)
dome_flange_gap >= 2       (flanges do not touch, with tolerance; bolts are inside the flange)
thruster_6_z    == cg_z    (strafe roll couple stays at zero)
```

With the endcap proposal, `bore_clearance` gives way to "the camera holes fit
inside the pilot ring" (`sled.md`); keep `dome_flange_gap`.

`thruster_6_z == cg_z` is the one that will drift: CG moves every time ballast or a
component moves. Re-check it after the float test rather than trusting the
sketch.

**Bay stack drives tube length:**

```
tube_length = dome_intrusion + pack_bay_length + electronics_bay_length + esc_bay_length + cap_allowance
            = 30 + 155 + 120 + 80 + 15    -> 400
```

- `pack_bay_length` 155 — two packs side by side, 100 of the 154 bore
- `electronics_bay_length` 120 — Pi 5 and Pixhawk side by side, 106 of the 154 bore
- `esc_bay_length` 80 — six ESCs ringed against the wall, not stacked in line

`sled.md` reorders the bays front to back as cameras → electronics → packs →
ESCs (was packs ahead of electronics), so the camera ribbons stay short and
far from the ESCs. The sum is unchanged. The dome centre is now measured
(on the lid's outer face, `sled.md`): on the acrylic lid the boards sit inside
the lid's thickness, so `dome_intrusion` is just the carrier and ribbon bends
behind the inner face — 30 is a comfortable allowance until the carrier is
drawn.

## Measure before cutting

Four of these five are sitting in boxes waiting on the inventory pass.

- [x] **ApisQueen U2 body OD and length** — **Ø70 × 96**, measured 2026-10-02.
      Mounting pad: four threaded brass inserts on a rectangle ~15.7 × 29.7
      centre to centre (caliper spans 13.5 / 17.8 and 27.3 / 32.1; holes
      Ø~2.2–2.4, thread size not yet identified)
- [ ] **One U2 ESC brick, L×W×H** — the swing factor in tube length, ×6
- [x] **Dome flange OD** — **71.9**, measured 2026-09-26. Over 70, so note 1
      stops holding and the baseline moves to 74 mm — see "Measured flange"
      above
- [ ] **YOWOO pack**, confirm against 155 × 50 × 37 in `power-budget.md`
- [ ] **Thruster mass, each** — for the buoyancy budget
- [ ] **Actual CG height**, from the float test — `thruster_6_z` follows it

## Related

- `sled.md` — camera mount, sled contents, stereo test plan
- `frame-and-mixing.md` — the BlueROV1 matrix these positions come from
- `open-questions.md` — the question this file answers
- `power-budget.md` — pack dimensions, buoyancy accounting
- ADR-012 — frame selection, still open
- ADR-003 / ADR-015 — dome port, camera architecture

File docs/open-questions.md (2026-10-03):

# Open Questions

## Sled, endcaps and CAD — decided vs proposed (2026-09-27)

Much of `sled.md`, the endcap proposal in `housing-layout.md` and
`cad/README.md` was written by an agent in design discussion. **Only the
first list below has Roland's approval.** Everything else is a proposal —
agents must not treat it as decided, build on it silently, or describe it
as settled. Visual: the "CARP Front-End Layout" artifact (side and front
views, cables up/down).

**Decided (Roland):**

- Domes stay on the front plate; cameras go on the sled so their cables
  connect outside the ROV.
- Rear end vacuum-held as well, with a mechanical backup, hardly ever
  opened.
- Aluminium lids are not v1 (cost); revisit later.
- CAD/ROS frame X forward, Y port, Z up; origin at the front pipe end on the
  tube axis.
- Onshape variable names: snake_case, whole words (`cad/README.md`).
- Camera board seats are print-only: slide-in rails (2026-10-02, after the
  tolerance coupons, `cad/README.md` §4).
- The bench rig should mirror the vehicle layout.

**Proposed, not approved:**

- Front lid vacuum-held on the pipe end with an O-ring, printed pilot ring,
  M6 tie rods on a 184 mm circle; 3/4" cast acrylic, 8" square.
- Bay order cameras → electronics → packs → ESCs; packs ride on the sled;
  the disconnect list; Bar30 on the front lid.
- Tray top at Z −55; `tube_length` 400.
- Stepped lid hole (Ø17 through, Ø52 × 8 counterbore) and the camera
  position chain (pupil 3 mm behind the lens front, board inside the lid).
- Stereo baseline stays 74 (could go to ~95).
- Cables up or down — **open, leaning up** (Roland).
- What holds the board at the rails' open end: printed detent, or a
  nut-held retainer (Roland's suggestion, 2026-10-02).
- Internal fan, Active Cooler, thermal soak before any aluminium.

## Blocking the build

**~~Thruster count: 4 or 6?~~ Resolved by purchase — six ordered 2026-08-19.**
The successor question is the frame: **SimpleROV-4/5 or BlueROV1?**
SimpleROV-5 uses five of the six (one spare) and keeps the simplest possible
bring-up. BlueROV1 uses all six for full 6-DoF — including pitch for camera
aiming with a stock matrix, no ArduPilot fork. Wiring must now budget ~56 A
peak either way, and the propulsion/hotel battery split (ADR-014) is live.

**Housing diameter and camera mounting — see `housing-layout.md`
(Leaning: 6" single housing, option B).** Four options drawn and dimensioned;
6" resolves tube diameter, camera mounting, and whether pitch is real in one
decision. Two findings from the drawing: the LiPos sit side by side in a
154 mm bore rather than stacked, and the six ESCs ring the tube wall instead
of eating axial length. Still no pipe bought — the proposal is gated on five
measurements listed in that file, four of which are in unopened boxes.

**Sub-question closed at 74 mm (2026-09-26).** The flange measured 71.9, not ~70, which broke 75; the bolt pattern (Ø64.5 circle, inside the flange) retired the old ≥ 5 mm gap rule, and 74 meets the rest (`housing-layout.md`, "Measured flange"). Original reasoning, assuming ~Ø70: **the stereo baseline is 75 mm.** Two ~Ø70 flanges
span 145 mm against a 154.1 mm bore, leaving 4.5 mm each side. At 85 mm
centers they do not fit the bore at all; at 100 mm they exceed even the tube
OD. The "~75–100 mm" carried in this file and the bring-up checklist was
never a range. 75 mm sits inside the 60–120 mm band `prior-art.md`
recommends for 0.5–2 m work, so the constraint costs nothing optically.

**Pi software stack — see ADR-017 (Leaning: vanilla OS, not BlueOS).**
Both design reviews flagged this as untracked. The live sub-question is the
base image: Ubuntu 24.04 (native apt ROS 2, but the Arducam Pivariety camera
stack is packaged for RPi OS only) vs Raspberry Pi OS (cameras turnkey,
ROS 2 in Docker). The CSI/encode bench prototype decides — Ubuntu first,
timeboxed; it must land before Phase 3 software integration.

**Rigging geometry — needs a drawing, not a debate.**
Boat → downline clip → ROV means effective horizontal radius ≈ tether length
minus depth (~15 m − 5 m ≈ 10 m at the first site), and navigation.md
("clip to downline") vs bom.md ("to the boat") is still unreconciled. One
sketch resolves the working radius, the attachment point, and the tether
length to actually buy (reviews 1 minor 3 / 2 minor 1 & 6).

**Is this still a $500 build?**
It is not. Worth deciding explicitly whether the target is "cheapest thing that
works" or "capable inspection platform," because they diverge from here.

## Deferred, revisit after first water

**Pitch control for camera aiming.**
No longer requires an ArduPilot fork — with six thrusters on hand, the stock
BlueROV1 frame provides pitch (see the frame question above). Value is real:
no tilt servo, no dynamic seal, no extra penetrator.

**Hotel/propulsion battery split.**
Live now that six thrusters are ordered. See ADR-014.

**48 V hotel power down a spare tether pair.**
Would give near-unlimited endurance for the load that actually drains the pack.
Not yet evaluated against penetrator count and isolation complexity.

**VESC on the vertical axis.**
FOC gives smooth thrust through zero, which is the axis whose jitter shows up
in imagery. ~$60–100. Only worth it if depth-hold jitter proves visible in
footage.

**Surface buoy instead of kayak tether.**
ADR-009's preferred architecture. Needs a float, GNSS, battery, and a WiFi/LoRa
link. Big usability win — paddle away and leave it working.

## Needs measurement, not decision

- **Actual thrust** per U2 in both directions, on a scale. Specs are optimistic.
- **Actual hover power draw.** The entire endurance model rests on a 10–15%
  duty estimate that hasn't been verified.
- **Ambient light at the site.** Camera in a jar at 5 m, midday and overcast.
  Validates the no-lights posture (ADR-004) before it's built around.
- **Whether the bottom has texture.** Optical flow lives or dies on this, and
  it's site-specific. Test at Massabesic before building around it.
- **Where sidescan contact error actually lives** — layback and GPS-to-transducer
  offset are usually the bigger terms than the receiver.

## Questions for CCOM

This is a personal project first; none of these are dependencies. Worth asking
opportunistically.

- Are there spare Pixhawks, penetrators, or housings in a drawer somewhere?
  Labs accumulate these.
- Is there a project fit — e.g. as a student platform? Would strengthen the
  case for Project11 conventions, but doesn't gate anything.
- Access to a pool or tank for the acoustic calibration (known-distance
  measurement to zero out fixed DAC/ADC buffer offsets).

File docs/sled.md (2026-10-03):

# Sled and Camera Mount

What rides on the slide-out sled, how the stereo cameras are held relative to
the domes, and how to test stereo before there is a housing to put it in.

**Status: proposal (2026-09-27).** Nothing drawn yet. The endcaps it hangs
from are in `housing-layout.md`, "Endcaps".

> **Decided vs proposed:** most of this file is agent proposals from design
> discussion, not approved decisions. `docs/open-questions.md` lists which
> is which — check it before treating anything here as settled.

## The idea in one paragraph

The front lid carries the domes on its outside face and the whole sled on its
inside face. Pulling the front lid pulls the sled: cameras, Pi 5, Pixhawk and
both packs come out as one assembly, and every camera cable stays connected on
the bench. The domes and cameras are both fixed to the lid and are never
separated by servicing, so the camera-to-dome geometry — the thing stereo
calibration depends on — is set once and does not move. Repeatability is a
property of the design rather than of how carefully it was put back.

## Datum chain

The optics care about camera-to-dome, nothing else. Keep that chain short and
keep the tube out of it:

```
dome ── dome bolt pattern (blind M2, lid outer face) ── LID ── dowels + screws (lid inner face) ── camera carrier ── camera boards
```

- The **lid** is the only reference. The pipe bore is out-of-round
  (prior-art.md) and never touches the optics.
- The **pilot ring** centres the lid in the pipe. That places the whole
  optical assembly in the vehicle, which matters for camera-to-vehicle roll and
  aim (clocking pin), not for calibration.
- The **tray** behind the carrier rides loose in the bore on skids, a few mm
  of clearance all round. If it fits tightly it fights the lid for location.

## Camera carrier

One printed part holding both cameras — the "one rigid plate" in `bom.md`.
Two separate brackets would let the cameras toe in or out relative to each
other, and a 0.1° change in relative aim costs more depth accuracy at range
than any baseline error does.

**Requirements**

| | Target | Why |
|---|---|---|
| Baseline | `stereo_baseline` (74 today — see "The baseline is no longer pinned") | Optical-axis to optical-axis, not board to board |
| Lateral: axis to dome centre | ≤ 0.2 mm, each camera | Decentring breaks the pinhole model the dome is meant to keep (prior-art.md). Sub-mm is what matters; 0.2 is a print-achievable aim, not a researched limit |
| Fore-aft: entrance pupil at dome centre | Adjustable ±3 mm per camera | prior-art.md: "Design fore-aft adjustability into the camera mounts." Domes and lenses vary |
| Relative aim | Parallel within ~0.5° | Calibration absorbs the rest; this keeps the overlap maximal |
| Board orientation | **Both identical, never mirrored** | The rolling shutter reads rows in the same direction on both, which is what makes the 23 µs sync (ADR-017) mean the same instant top to bottom. A board rotated 180° reads bottom-up and the sync falls apart. Identical orientation also puts both 1.3 mm axis offsets on the same side, so hole-pattern spacing equals `stereo_baseline` |
| Sensor rows | Parallel to the baseline | Rectification assumes it; mechanical roll within ~1°. Check which board edge the rows run along — the STEP does not say |

**Holding each board**

- **Print-only: slide-in rails** (chosen 2026-10-02 from the tolerance
  coupons, `cad/README.md` §4; print-only decided 2026-09-27). The mount has to hold each board
  *located and clamped* — no shift, rock or lift when the lens is turned for
  focus or a ribbon is tugged — or the calibration walks. For the bench rig
  stability is what matters (calibration measures where the boards are); the
  ≤ 0.2 lateral target only bites on the vehicle carrier, lens to dome.
  Candidates, all printed, none bought:
  - **Slide-in rails:** each board slides edgewise into two grooves
    (board 1.7 + 0.1, coupon A) against an end stop. Located by edges and
    groove. Open end: a small printed detent, or a retainer held by a
    printed nut (Close preset, coupon B) that could also clamp behind the
    connector against ribbon pull — **open** (retainer suggested by Roland
    2026-10-02). Needs ~1 mm of component-free board edge on the front — check in
    the STEP.
  - **Locate + snap-on retainer:** printed pins (two diagonal holes,
    Ø~1.8–1.9 in the Ø2.0 holes) or a shallow pocket locate; one PETG plate
    with lens-barrel holes snaps over **both** boards, presses them onto the
    standoffs and bears on the connector end against ribbon pull.
  - **Retainer + printed thumb-nut:** the same retainer plate held by one
    printed nut on a printed stud (≥ M6-class threads print reliably; M2
    does not). Adjustable clamp force, no snap to tune, reusable.
  - **Split snap pins** through the board holes, tapered with a lip that
    snaps over the board: the usual print-only PCB mount, but examples use
    ~3 mm holes and resin; at Ø2.0 in FDM each half-pin is ~0.7 wide —
    probably too fragile.
  - **Filament pins** (1.75 mm filament pressed into the carrier) or
    heat-staking — stronger than printed Ø1.8 pins; set aside for now.
  - Fallback: M2 screws into heat-set inserts.

  The tolerance coupon should decide it: rail grooves at 1.7 + 0.1 / 0.2 /
  0.3, printed pins at Ø1.8 / 1.85 / 1.9, one cantilever latch in PETG, and a
  printed nut on a stud.
- The hole pattern sits 1.3 mm off the dome axis, toward the connector
  (`cad/vendor/README.md`: the optical axis is off-centre, away from the
  connector).
- **Fore-aft = spacers, focus = the lens thread.** Two separate adjustments:
  the spacer stack under the board puts the entrance pupil at the dome centre;
  the M12 thread then sets focus (Blue Robotics' recipe: ½–¾ turn CCW from air
  focus, then iterate wet). Print spacer sets in 0.5 mm steps; the board's
  back-side parts stand ~2 proud, so the thinnest spacer is ≥ 2.5.
- Once tuned, lock the lens thread (a dab of nail varnish or a printed
  clamp — **no threadlocker near the acrylic lid**, uncured Loctite crazes it)
  and don't touch the spacers again. Re-calibrate if either changes.

**Carrier to lid**: two steel dowels in reamed blind holes in the lid's inner
face, plus 3–4 screws into blind tapped holes. Nothing through the lid (see
the lid rules below). The dowels make the carrier removable without losing
calibration, though in normal servicing it never comes off.

**Material**: PETG, or better a CF-filled nylon or PETG (the Centauri Carbon 2
has the hardened nozzle). **Not PLA** — it creeps when warm, and this part
lives next to a Pi that ran at 64–85 °C on the open bench (ADR-015). Rib it
across the baseline; stiffness across that span is what holds relative aim.

## The board sits inside the lid

Measured 2026-09-27 (`cad/README.md` §1 has the readings and the arithmetic):

- **The dome is a hemisphere, R 26.3** (glass OD 52.4, ID 47.25, wall ~2.6).
  Height from the flange's back face to the apex is 26.7, so the **centre of
  curvature sits ~0.4 in front of the flange's back face** — on the lid's
  outer face, plus any gasket under the flange.
- **The flange is 2.0 thick.** The "3/8" flange" in the listing is its
  radial width, (71.9 − 52.4) / 2 ≈ 9.75, not its thickness. The flange cannot
  clip the 141° cone: the 70.5° edge ray leaves the glass ~8.8 above the
  centre, the flange top is at ~1.6.
- **The lens front stands 17.0 in front of the board** at the current focus
  (the STEP said ~16), and the entrance pupil is a few mm behind the front
  element.

So with the pupil at the dome centre, the board's front face lands **~12–15
behind the lid's outer face**, and its back-side parts reach ~15.5–18.5. With
the 3/4" (19 mm) acrylic lid the whole board sits **inside the lid's
thickness**. With the 3/8" (9.5 mm) aluminium upgrade it sits behind the inner
face.

Two consequences:

1. **The camera hole is stepped, not straight.** The pupil sits at the outer
   face and the whole field opens forward into the dome, so the outer part of
   the lid only has to pass the **Ø14 lens barrel**: a **Ø16–18 through-hole**,
   with a light chamfer on the outer edge in case the pupil turns out to sit
   behind the face. The board, connector and ribbon go in a **Ø52 counterbore
   from the inside, ~8 deep** (the board needs 4.5–7.5 of it; the rest is
   margin for the fore-aft tune). From the optical axis the board reaches 7.3
   away from the connector, 16.7 + 8 of connector and ribbon on the connector
   side, ±12.5 across — Ø52 clears that and leaves ~5 of acrylic to the
   dome's bolt holes. The **whole flange face stays intact** for the dome
   seal, which a straight Ø52 hole would have cut down to a ~5 mm land.
   - The 8 needs the ribbon **bent back tightly at the connector** — a 1–2 mm
     radius, not a crease, a few mm clear of the latch, bent once. A loose
     bend measured 12.5 and would push the counterbore to ~Ø58, 2 mm from the
     bolt holes. The carrier clamps the ribbon behind the bend so a tug in
     assembly can't unlatch or re-bend it.
2. **Lid thickness is in the chain.** Swapping acrylic for aluminium moves
   the camera ~9.5 mm relative to the inner face, and the counterbore goes
   away. Make `lid_thickness` a driving variable, and put the difference in one printed
   spacer between carrier and lid, so the swap is a new spacer plus a re-tune,
   not a new carrier. The carrier's board seats reach forward into the
   counterbore on the acrylic lid.

## The baseline is no longer pinned

`housing-layout.md` fixed the baseline at 74 because the dome flanges had to
fit **inside the bore**. With a flat lid on the pipe end they don't — the
flanges sit on the lid's outside face, and only the camera holes and the
carrier have to be inside the pipe. The new limits:

| Constraint | Limit on `stereo_baseline` |
|---|---|
| Flanges don't touch (`dome_flange_gap >= 2`) | ≥ 74 |
| Camera counterbores (Ø52) inside the pilot ring (~Ø147 ID) | ≤ ~95 |
| Flanges inside an 8" lid (tie rods at 45° never interfere) | ≤ ~130 |
| Carrier inside the pilot ring | ≤ ~112 |

So the baseline can be anything from **74 to ~95**. Depth precision at range
scales with baseline: 95 over 74 is ~28% finer at 2 m, with some loss of
overlap at 0.5 m — little, with 141° lenses. It is also more room between the
flanges to get a screwdriver in.

**This is a decision, not a free parameter — make it before cutting the
lid.** Everything that currently says "74" (`bom.md`, `housing-layout.md`,
`open-questions.md`) says it because of the bore, and that reason has gone.

## Lid rules

The lid is pressure boundary. Inside the pipe seal it is dry on the inside
and wet on the outside, so:

1. **Nothing passes through the lid inside the seal** except the two dome
   holes and any glands. Every other fastener goes into a **blind** hole:
   - dome screws (M2) from the outside face — they only locate the dome,
     vacuum and depth hold it;
   - carrier screws and dowels from the inside face.
2. In 19 mm acrylic, blind taps up to ~10 deep: M4 or M5 coarse is fine for
   the carrier, M2 is weak but only has to locate a dome. Zero-rake drill,
   slow, cooled.
3. Tie-rod holes (Ø184 circle, 45°) are **outside** the seal, so they can go
   through.

## What rides on the sled

**Order changes: cameras → electronics → packs → ESCs.** `housing-layout.md`
had packs forward of the electronics. With the Pi on the sled right behind
the cameras, the stock 150 mm FFCs that came with the cameras may reach
without any extension, and the ribbons end up as far from the ESCs as the
tube allows — prior-art.md's documented EMI failure mode.

| On the sled | Notes |
|---|---|
| Camera carrier + both B0444s | Bolted to the lid |
| Pi 5 (+ M.2 HAT, NVMe) | Directly behind the carrier. If the Pi needs the aluminium lid as a heatsink, a short thermal strap to the lid is the path |
| Pixhawk | Beside the Pi (the 106-of-154 side-by-side in `housing-layout.md`) |
| Pololu 5 V regulator | Hotel pack → Pi |
| Hotel + propulsion packs | Side by side, low. Charged **outside** the tube, which a sled makes easy — a lithium pack is never charged inside a sealed tube |
| SOS leak sensor + probes | Probes on the tray's underside, one forward and one aft — the tube's low point moves with the sled's weight |

**Stays in the tube (rear):** the six ESCs, their phase wires to the rear-lid
penetrators, the tether penetrator, the Schrader stem. Phase wiring — 18
conductors — never crosses a disconnect.

**Disconnects the sled crosses** — all made through the front opening with
the sled pulled partway out, so each needs ~150 mm of service loop:

| Line | Connector | Notes |
|---|---|---|
| Propulsion pack → ESC bus | XT90-S (already stocked) | Anti-spark; it is also the arming connection |
| Pixhawk MAIN OUT 1–6 → ESCs | One multi-pin signal connector | Signal + ground only (`wiring.md` rule 3) |
| Tether Ethernet → Pi | RJ45 into the Pi, or an inline coupler | |
| Bar30 → Pixhawk I2C | JST-GH ↔ GH (the Blue Robotics adapter set) | **Or move the Bar30 to the front lid** and drop this one — it is a potted penetrator either way, and on the front lid it comes out with the sled |

**Tray**: flat, under the centreline so the packs sit low (ballast low, as
the BG target wants). A 100-wide pack pair fits the 154 bore at up to ~58 below
the axis. Printed PETG skids on the bore. It is cantilevered from the lid only
when out of the tube; on the bench it rests on its skids.

**CG moves aft** a little with the packs behind the electronics. `thruster_6_z ==
cg_z` in `housing-layout.md` already says to re-check after the float test;
this is one more reason.

## Testing stereo before the housing exists

Three stages. Each one uses the same carrier, so later stages test the
vehicle hardware rather than a stand-in.

1. **Air, now.** Print the carrier and a flat stand-in plate with the lid's
   hole pattern. Cameras on the stock 150 mm cables to the bench Pi. Checks
   the rig is rigid, calibration converges, the calibrated baseline matches
   `stereo_baseline`, sync holds (ADR-017), and depth on a known target is right.
   Air calibration does **not** carry over to water — this validates the rig
   and the pipeline, not the numbers.
2. **Domes in water, no housing — the "glass-bottom" rig.** Drill the real
   acrylic front lid, mount the domes, bolt on the carrier, and lay the lid
   **horizontally across a tote of water, domes down**. The cameras stay dry
   on top; only the domes and the lid's outer face are wet, under a few cm
   of water, so no pipe seal is needed. This is where to:
   - set fore-aft per camera, using the GEOMAR trick: checkerboard
     half in, half out of the water, adjust until there is no refraction
     discontinuity at the waterline (prior-art.md);
   - focus wet;
   - calibrate underwater with the laminated checkerboard, at 0.5–2 m.
3. **Sealed, in the vehicle.** Close up and re-calibrate. It should match
   stage 2 — the lid, domes and carrier never came apart. If it doesn't,
   something in the chain moved, and that is worth knowing before a dive.

## Modelling order (Onshape)

1. Lid: outline, pilot ring, tie-rod circle, stepped camera holes
   (`lid_hole_diameter` through, `lid_counterbore_diameter` counterbore from inside) and blind M2
   patterns — driven by `stereo_baseline`, `dome_bolt_circle_diameter`, `lid_thickness`, `tie_rod_circle_diameter`.
   Model the drilling jig from the same sketch: one jig for acrylic and
   aluminium (`housing-layout.md`, "Endcaps").
2. Domes (measured) and B0444 STEPs (`cad/vendor/`) placed, dome centre
   marked on the lid's outer face.
3. Carrier: camera pockets, 1.3 mm axis offset, spacer stack, dowels to lid.
4. Stand-in plate for stage 1 (same hole pattern, printable).
5. Tray, skids, disconnect positions — after the carrier works.

## Measure / decide before cutting the lid

- [x] **Dome height `H` and glass OD** — 26.7 and 52.4, measured 2026-09-27:
      hemisphere, centre on the lid's outer face, board inside the lid
- [x] **Dome glass inner opening at the flange** — 47.25; moot now the lid
      hole is stepped (Ø16–18 through, Ø52 counterbore from inside)
- [x] **B0444 board, holes, lens height, connector** — measured 2026-09-27,
      `cad/README.md` §1
- [x] **B0444 sensor row direction** relative to the connector edge — rows
      run parallel to it (along the 25 mm side); cables-up is upright.
      Inferred from bench frames, `cad/README.md` §1
- [x] **Lens entrance pupil** — **left to the stage-2 wet tune** (decided
      2026-09-27). Start with the pupil assumed ~3 mm behind the front
      element and set the first spacer from that; the ±3 mm spacer range and
      the counterbore margin absorb the error. Keep the chamfer on the
      Ø16–18 through-hole in case the pupil lands behind the outer face
- [ ] **`stereo_baseline`: stay at 74 or go wider (≤ ~95)?**
- [ ] Bar30 on the front lid or the rear?

## Related

- `housing-layout.md` — tube, endcaps, frame geometry
- `cad/vendor/README.md` — B0444 dimensions
- `prior-art.md` — dome focus, calibration, ribbon EMI
- ADR-003 (domes), ADR-015 (camera measurements), ADR-017 (stereo sync)

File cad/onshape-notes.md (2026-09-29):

# Onshape — notes for agents

Researched **2026-09-27** so later sessions don't have to redo it. Onshape
ships every ~3 weeks; before relying on anything version-specific, check the
newest "Improvements to Onshape — <date>" post on forum.onshape.com and the
API changelog (links at the bottom). Update this file when you do.

## What an agent can and can't do here

**No agent in this repo can drive the Onshape GUI.** The user models; the
agent plans, sets dimensions, reviews, and analyses exports. Four ways to go
further, in order of cost:

1. **Guide the user.** Give numbered steps with named Onshape features
   (Sketch, Extrude New/Add/Remove, Hole, Linear pattern, Variable,
   configurations) and the exact dimension expressions (`#stereo_baseline/2`). The
   user has "dabbled" — explain concepts once, briefly.
2. **Analyse exported geometry locally.** The user exports STL/STEP to
   Windows `Downloads` (`/mnt/c/Users/roland/Downloads` from WSL). Recipe that
   works, in the session scratchpad (the system Python has no numpy):

   ```bash
   python3 -m venv venv && ./venv/bin/pip install -q numpy scipy networkx shapely rtree trimesh matplotlib
   ```

   `trimesh.load()` for bounds/volume/`split()` into bodies; `m.section()` for
   cross-sections; matplotlib `Poly3DCollection` to render PNG views you can
   then Read. `split()` needs scipy or networkx installed.
3. **FeatureScript MCP Server (Onshape Labs, early access, July 2026).**
   Official. Lets Claude write, test and refine **custom features**
   (FeatureScript in a Feature Studio) from natural language — a
   text → code → CAD route. It is not documented as a general "edit my Part
   Studio" tool. Setup, per Onshape's tech tip:
   - subscribe to **FeatureScript MCP Server** in the Onshape App Store;
   - `claude mcp add --transport http onshape https://fs-mcp.labs.onshape.app/mcp`;
   - authorise in the browser when Claude Code prompts; `/mcp` to
     re-authenticate if its tools vanish.

   It writes into the user's documents — **ask before setting it up.** Cost
   was not stated. App Store app calls do not count against the API quota.
4. **REST API with the user's keys.** Keys now live in the user's Onshape
   preferences (moved from the dev portal, rel-1.204). **The quota is tiny on
   Free/Standard: 2,500 calls per user per year** (~7/day), counted for API
   keys and private OAuth apps, including API Explorer calls; exceeding a rate
   limit returns HTTP 429. Never poll; batch; prefer one export over many
   reads. Third-party MCP servers (e.g. `altendky/onshape-mcp`,
   `Casys-AI/mcp-onshape`, `onshape-claude-bridge`) exist but are unvetted and
   spend this same quota.

## Plans (as of 2026-09)

| Plan | Price | Relevant terms |
|---|---|---|
| Free | $0 | **Non-commercial, documents are public.** API 2,500 calls/user/yr. A third-party page claims a 10-document / 100 MB private cap — unverified against Onshape's own terms |
| Standard | $1,500/user/yr | Private storage, support. API 2,500/user/yr |
| Professional | $2,500/user/yr | PDM, simulation, rendering, CAM. API 5,000/user/yr |
| Enterprise | custom | API 10,000/full user/yr |

The user's plan isn't recorded. CARP's GitHub repo is public, so public
Onshape documents don't expose anything new.

## API

- Current version **V17** (rel-1.220, 2026-08-28). V13–V16 landed Jan–May
  2026 (V16: assembly suppression states).
- **Direct export** endpoints for Part Studios and Assemblies to STEP, glTF,
  OBJ, SolidWorks (rel-1.199); STL has a `mode` parameter (rel-1.195); async
  STEP export for Part Studios (rel-1.198).
- 19 new webhook event types (rel-1.221), mass properties with named
  positions, material library endpoints.

## 2026 product changes worth knowing for this project

| When | Change | Why it matters here |
|---|---|---|
| Jan 9 | Revolve gains Up to Next / Part / Vertex / Face | Dome and pilot-ring modelling |
| Mar | Named assembly positions link to in-context features | Sled in/out positions |
| Jun 5 | Routing curves with a target length | FFC / cable length from the CAD path (`bom.md` pending cable row) |
| Jun 26 | Asynchronous simulation | Lid flex check if ever wanted |
| Aug 28 | **Variable Studio parameters readable from FeatureScript** | Custom features can use `stereo_baseline` etc. directly |
| Aug 28 | Orient normal to sketch (auto camera); resize planes to bounding box | Beginner friendliness |
| Aug 28 | New Learning Center course: **Introduction to Configurations** | Spacer-thickness configurations (`cad/README.md`) |
| Sep 18 | Reset configurations to defaults; view-only document mode; filter by warnings; configurable section-view interference colour | Safer review of the user's documents |
| Sep 18 | **URDF export can emit GLB meshes** | ROS 2 robot description for the vehicle, later |
| Sep 18 | Dynamic suppression in assemblies (suppress parts/patterns/mates from values) | Acrylic vs aluminium lid variants in one assembly |
| 2026 | AI Advisor in-app (help, best practice, troubleshooting); roadmap: LLM-assisted FeatureScript, AI search, AI quick render, AI agents as project members | Point the user at AI Advisor for "how do I…" questions |

## Gotchas seen in this project

- **Extrude "New" vs "Add".** The user's practice Pi 5 holder
  (`prints/pi_bracket.stl`) exported as ~11 overlapping solids (plate,
  standoffs, pins) that were never merged, so the STL is not watertight.
  The slicer coped and it printed, but tell the user to use *Add* (or a
  Boolean union) so each printed part is one solid.
- **Never Mirror a camera seat** — use Linear pattern or a transform copy.
  Mirroring flips the 1.3 mm optical-axis offset and the connector side
  (`docs/sled.md`: both boards must be identical, not mirrored).
- Units: everything in this repo is mm; say so in every dimension you hand
  the user.
- **Printed threads: the Plastic Thread custom feature** (william_knoblauch,
  [doc](https://cad.onshape.com/documents/7a5d17f7ab4323f51774364f/v/40e5786c17172c1c23f38138/e/31ca9e4b737302343e72270b)).
  Onshape's Hole threads are cosmetic only. Add it by pasting that link in
  *Add custom features → Other documents*; searching "plastic threads"
  mostly finds greyed-out documents that only use it. Select the stud's
  cylinder and the nut's hole together so the threads match; presets
  Close / Normal / Loose.
  - **Draw the hole at the nominal size (Ø6 for M6), not the minor
    diameter.** The feature builds the internal thread around the selected
    hole; a Ø4.9 hole gave an "M4.9" nut that interfered with the M6 stud
    by ~0.5 on diameter (coupon B, 2026-09-28).
  - Its *View* panel (pitch, TPI, min layer) is read-only and did not
    reflect the Advanced-tab inputs (showed 3.175 pitch for a 1 mm thread,
    min layer blank). Measure the geometry instead.
  - Measured clearance on M6 × 1.0 (radial, per side): Close 0.22, Normal
    0.28, Loose 0.33.
- **Copy-pasted sketch text keeps the original string** — edit every
  pasted label (coupon A shipped three "1.85" pin labels at first).
- **A sketch hides itself once a feature consumes it.** To reference its
  geometry from a later sketch (e.g. a pattern centreline), show it with
  the eye icon in the feature list.
- **Check exported STLs locally.** The user's Windows Downloads is
  `/mnt/c/Users/roland/Downloads/`; parse the binary STL in Python
  (bounding box, Z levels, per-part split by shared vertices, thread radii)
  — it caught a 5 mm-for-0.5 mm pin height and the undersized nut threads.

## Sources

- Release posts: [Sep 18](https://forum.onshape.com/discussion/31763/improvements-to-onshape-september-18-2026),
  [Aug 28](https://forum.onshape.com/discussion/31629/improvements-to-onshape-august-28-2026),
  [Jun 26](https://forum.onshape.com/discussion/31232/improvements-to-onshape-june-26-2026),
  [Jun 5](https://forum.onshape.com/discussion/31101/improvements-to-onshape-june-5-2026),
  [Jan 9](https://forum.onshape.com/discussion/29760/improvements-to-onshape-january-9th-2026),
  [March highlights](https://www.onshape.com/en/blog/cloud-native-cad-software-automatic-updates-new-features)
- [API changelog](https://onshape-public.github.io/docs/changelog/) ·
  [API limits](https://onshape-public.github.io/docs/auth/limits/)
- [FeatureScript MCP + Claude Code tech tip](https://www.onshape.com/en/resource-center/tech-tips/connect-featurescript-mcp-server-claude-code) ·
  [Getting started with the FeatureScript MCP Server](https://www.onshape.com/en/blog/get-started-featurescript-mcp-server)
- [AI in Onshape](https://www.onshape.com/en/blog/ai-artificial-intelligence-cloud-native-cad-pdm-platform) ·
  [Pricing](https://www.onshape.com/en/pricing)

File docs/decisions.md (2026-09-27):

# Architecture Decision Records

These records came out of an early brainstorming session and were originally
all stamped "Decided." Most were not. Status now reflects actual commitment:

- **Committed** — hardware ordered or otherwise costly to reverse.
- **Leaning** — reasoned position, nothing bought, cheap to change.
- **Open** — actively contested; see `open-questions.md`.

Format: decision, rationale, consequences, status.

---

## ADR-001 — Design depth 5 m (v1, first site)

**Leaning.** 5 m is the depth of the particular section of Massabesic slated
for the first investigations — a v1 scope choice, not the vehicle's ceiling.
Deeper sites are expected later.

At 0.5 bar gauge the housing is not crush-limited; failures will be seal
workmanship, not structural. 4" sched-40 PVC is overbuilt by an order of
magnitude. Leak testing via a Schrader stem in one endcap: **vacuum test is
the gate** (15 inHg with the hand pump, core removed — loads seals the same
direction depth does; 15 inHg ≈ 5.2 m of water — matches the site depth,
where 10 inHg would only prove 3.5 m), gentle bike-pump pressure + soapy
water only to *localize* a leak after a failed vacuum test (positive
pressure unseats face seals, so it's a debug tool, not a pass/fail check).

**Consequence:** Flotation can be sealed air voids (~1 g/cm³ lift) rather than
syntactic foam (~0.4). Budget freed for optics.

**Shallow assumptions to re-check before a deeper site** — several records
lean on "it's only 5 m":

- ADR-002 — surface-on-power-loss as the entire recovery plan
- ADR-009 — snag recovery workable from the surface
- Tether length (15 m working radius) and the buoy's ~8 m vertical hang
- Shallow-water multipath handling in acoustic ranging (`navigation.md`)

The Bar30 (ADR-006) already covers 300 m and the housing has margin to several
tens of metres, so depth growth is mostly a seals, tether, and recovery-plan
question — not a rebuild.

---

## ADR-002 — Vehicle is set slightly positive

**Leaning.** Power loss results in surfacing. At 5 m this is the entire
recovery plan.

---

## ADR-003 — Dome port over flat port

**Leaning.** All imagery will be at 0.5–2 m range. Flat-port edge chromatic
aberration and FOV loss are worst at close focus, which is the entire operating
regime. Also preserves future photogrammetry options.

---

## ADR-004 — Ambient light first; no lights on v1

**Leaning.** Reversed 2026-08-20 from "lights on offset arms."

The v1 site is 5 m deep, worked in daylight. At Kd ≈ 0.7–1.0 (consistent with
3 m visibility), 5 m keeps ~1–3% of surface light — hundreds to thousands of
lux on the bottom. A fast lens and a sensitive sensor can use that; adding our
own light next to the camera re-lights the particulate column that ambient
leaves dark.

**Wins:** the backscatter problem vanishes (ambient arrives from above,
already diffuse); hotel load drops 20–40 W — the power budget's dominant
term — extending endurance per pack ~30–40%; two or three penetrators and the
light arms disappear from the build.

**Costs:** the shadowed side of structure is invisible — the one strong
argument for carrying a single small diffuse light, off by default. Ambient
dies exponentially with depth, so deeper sites (ADR-001) will need lights,
full stop. In direct sun the vehicle's own shadow moves with the down
camera's frame; features on its edge report zero motion and must be masked
out of optical flow.

**Hardware consequence:** camera selection prioritises sensitivity and true
manual gain (large/BSI pixels, fast glass) over convenience.

**Superseded reasoning, kept for the day lights return:** backscatter, not
lumens, is the limiting factor — arms 30–40 cm off-axis, toed in so beams
cross the camera cone ~1 m out; the down-looking nav camera is the exception
and wants flat, near-coaxial, diffuse light, since moving off-axis shadows
read as platform motion to optical flow.

**Verify before first water:** camera in a jar at the site, midday and
overcast. This is a measurement, not a debate.

---

## ADR-005 — Battery onboard, tether is Ethernet-only

**Leaning.** Topside power means fat conductors, voltage drop, and a tether
that can't be managed one-handed from a cockpit. Ethernet-only tether is thin,
near-neutral with floats, low drag.

**Open sub-decision:** pushing 48 V down a spare pair to carry hotel load only
(thruster transients stay on the onboard pack). Not yet evaluated.

---

## ADR-006 — Bar30 depth sensor, not Bar02

**Committed** — sensor ordered. Reversed from an earlier preference for the
MS5837-02BA.

Original reasoning was resolution. That reasoning was wrong: the 30BA gives
~0.2 mbar ≈ **2 mm** of water, and the 02BA ~0.16 mm. Both are far below the
real noise floor from surface chop and thruster wash.

The 30BA is what every ArduSub build uses, avoids any question about which
stable release picked up 02BA auto-detection, and gives 300 m of range if the
vehicle ever ends up deeper than planned.

**Note:** ArduPilot master *does* support the 02BA — the MS5837 driver reads
pressure sensitivity from PROM and dispatches to separate `_calculate_5837_02ba()`
or `_calculate_5837_30ba()` paths, with distinct device types (0x18 vs 0x12).
Verify the reported device type after connecting; misidentification fails
*silently* with plausible-looking wrong depth.

**Config:** `BARO_EXT_BUS` defaults to −1 (disabled) and must be set to the
external bus index. This is the most likely cause of "depth sensor not
detected" reports.

---

## ADR-007 — No safety switch

**Leaning.** Cannot press a physical button inside a sealed tube. Set
`BRD_SAFETYENABLE = 0`. Alternative was an external switch with its own
penetrator; not worth the hull penetration.

---

## ADR-008 — Pixhawk (FMUv2) + separate Pi, not Pi+Navigator

**Committed.** Radiolink Pixhawk Advanced, ordered from RobotShop.

Rejected the Blue Robotics Navigator ($220 + $65 Pi) on two grounds:

1. **Cost** — $285 of a $500 budget for the FC alone.
2. **Architecture** — Navigator runs ArduSub on the Pi under Linux with PWM
   from a PCA9685 over I2C. That's a soft-real-time control loop sharing cores
   with the payload. This build plans LK optical flow at 30 Hz *and* chirp
   cross-correlation on 96–192 kHz audio. Those are exactly the loads that
   contend with the flight loop.

**Why Radiolink over a 2.4.8 clone:** real manufacturer with automated SMT
assembly rather than an anonymous factory, sold through a real distributor.
Still FMUv2 — the architecture ArduSub actually tests.

**Why not Holybro 6C:** FMUv6C is less-tested for Sub. ArduPilot docs state
only the Pixhawk 1 is fully tested. Issue #23310 ("Sub: Pixhawk 6c full
support") remains open since March 2023, last touched Feb 2024.

**Known consequence:** FMUv2 flash ceiling. ArduPilot has been trimming
features from these boards for years. Fine for ArduSub today; this is a board
near the end of its life.

**Expected quirk:** power module voltage reads low on some units. Calibrate
`BATT_VOLT_MULT` against a meter rather than trusting defaults.

**Field intel (2026-08-20, see `prior-art.md`):** BlueOS explicitly warns
against RadioLink boards (proprietary bootloader), and community experience
says the clone FC — not the cheap thrusters — is what fails first in budget
builds (compass grief, EKF weirdness). Mitigations: flash `Pixhawk1-1M`
Sub/stable via QGC custom firmware, **keep the working .apj pinned locally**,
mount the compass away from ESC wiring, and connect Pixhawk→Pi over USB
(BlueOS only auto-detects over USB, not UART). Note AP_DDS and Lua are
compiled out of 1 MB builds — ROS 2 lives on the Pi over MAVLink.

**Cost note, on record:** actual price paid was $159.82 + shipping, not the
~$60 street price assumed when this was argued. Against the Navigator's $285
the cost gap (ground 1) was much thinner in practice; the architecture
argument (ground 2 — hard-real-time FC separate from the DSP-loaded Pi) is
what carries this decision.

**Bench evidence (2026-09-26): this board has 2 MB of flash.** Running the
`Pixhawk1-1M` build, ArduSub 4.7.1 logs `2M flash - use Pixhawk1 firmware`
on every boot (board ID `002A0032 35335103 33303831`). The 1 MB ceiling above
does not apply to this unit. **Reflashed to the full `Pixhawk1` build the
same evening** — it boots clean, no warning, calibration and parameters
carried over. It adds 91 parameters: Lua scripting (`SCR_ENABLE`),
mount/gimbal (`MNT1_*`), IMU temperature calibration, a third harmonic
notch, more filters, proximity. It does **not** include AP_DDS (no `DDS_*`
parameters), so ROS 2 over MAVLink on the Pi stays the plan. QGC's
`Unsupported FTP: 16` persists on the full build, so that is a QGC/ArduSub
FTP mismatch, not a 1 MB cut. Still one IMU on the full build (MPU6000,
`INS_ACC2_ID = 0`): this board has no second IMU, or it is dead — no backup
IMU either way.

---

## ADR-009 — Stay tethered; reject HROV/AUV hybrid

**Leaning.** The buoy variant below is still just an idea — see
`open-questions.md`.

The mechanical cost of tetherless is near zero (battery is already onboard,
ArduSub already runs missions). The real costs:

- **Loses one-way acoustic ranging.** Sub-meter positioning was plausible
  *because* Ethernet time sync removes transponder turnaround jitter.
  Untethered means two-way ranging with tens of ms of USB audio slop — tens of
  metres of range error.
- **Nothing bounds nav drift.** VO is a random walk, and over featureless mud
  it doesn't drift so much as stop working.
- **The usual HROV justification doesn't apply.** Tether fouling on wreck
  structure is real, but at 5 m a fouled tether is recoverable without
  abandoning the vehicle. **Snag protocol (2026-08-20, replaces an earlier
  "free-dive to clear it" line):** gentle haul-test from multiple bearings →
  slack the tether and drive the vehicle to unwind it → if still fouled,
  buoy the tether end and come back with a second person or a grapple.
  **Never solo breath-hold dive on a fouled line** — the line that snagged
  the vehicle is the line that snags the diver. The vehicle costs ~$1,600;
  it is not worth a solo entanglement dive, ever.

**Adopted alternative:** tether to a surface buoy carrying GNSS, battery, and
a WiFi/LoRa link, with ~8 m hanging vertically. Untethered *from the kayak*,
which is the part that's actually unpleasant, while preserving Ethernet,
absolute position, and a visible recovery marker.

**Software consequence:** build the vehicle to own its own mission with the
topside as a view, not a dependency. Tether dropout becomes a degraded link
rather than a lost vehicle.

---

## ADR-010 — Project11 interfaces, not Project11 autonomy

**Leaning.** CARP is a personal project first; CCOM use is an option to keep
open if a fit emerges, not a dependency.

**Transfers cleanly:**
- `udp_bridge` — built for exactly this failure mode (unreliable vehicle↔operator link)
- Project11 message types and the helm abstraction, so CARP appears in the same
  operator station as the EchoBoats
- rosbag and diagnostics conventions — what makes an inspection tie back to a
  sidescan contact later

**Does not transfer:** `mission_manager`, `path_follower`, Nav2 overlay. All
assume track lines in a 2D world frame with a GNSS position solution. CARP has
depth, heading, and dead-reckoned velocity — no global fix. Feeding those
planners a random-walk position produces confidently wrong behaviour.

**Rationale beyond the technical:** bare mavros plus a few nodes would be
simpler in isolation. But a vehicle speaking EchoBoat interfaces keeps the
option of CCOM/student use open at little extra cost. That's a side benefit,
not the goal — if the conventions ever fight the build, the build wins.

---
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

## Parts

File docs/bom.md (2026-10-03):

# Bill of Materials & Procurement Tracker

One row per part: quantity, source, estimated cost, what was actually paid,
and status. **Est** is a planning number; **Paid** is filled in when the order
is placed. Statuses: `ordered` → `received` → installed; `pending` = not yet
bought; `later` = deliberate deferral.

## Ordered

| Item | Qty | Source | Est $ | Paid $ | Status | Notes |
|---|---|---|---|---|---|---|
| Radiolink Pixhawk Advanced | 1 | RobotShop | 60 | 159.82 | received | FMUv2 / STM32F427. **Not** the Radiolink Pixhawk 4 — that one is ArduPilot-incompatible (proprietary binaries, wrong connectors). Shipped separately, +8.92 shipping |
| Pololu D36V50F5 | 1 | RobotShop | 25 | 39.95 | received | 5 V @ 5.5 A. Honest ratings, real thermal path |
| Digital RC servo tester | 1 | RobotShop | 20 | 10.74 | received | Manual mode holds settable pulse width, 2 µs resolution, PPM passthrough display |
| Bar30 pressure sensor (Blue Robotics R2) | 1 | RobotShop | 85 | 90.00 | received | MS5837-30BA, potted in penetrator. See ADR-006 |
| 4S 6000 mAh LiPo (YOWOO, 100C, XT90-S) | 2 | Amazon | 84 | 131.98 | received | 65.99 ea. Anti-spark XT90-S as specified in ADR-013 |
| Dual LiPo balance charger/discharger, 10 A | 1 | Amazon | 60 | 67.19 | received | |
| XT90-S pairs w/ 150 mm 10 AWG pigtails (Amass) | 3 pr | Amazon | 12 | 14.99 | received | Pigtails help but bulk 10 AWG still needed |
| XT90 male → XT60 female adapters (OliRC) | 3 | Amazon | 8 | 8.99 | received | Charging only (6 A, nowhere near limit) |
| ApisQueen U2 + ESC, 3.75 lbf | 6 | Amazon (ApisQueen) | 390 | 389.88 | received | 64.98 ea, two line items of 3. **Verify handedness on arrival** — counter-rotating pairs needed and the two listings carried identical titles |
| Raspberry Pi 5 8 GB | 1 | Amazon (MemoryWhiz, 3rd party) | 110 | 200.00 | received | $175 at PiShop — ~$25 premium for fast arrival. Third-party seller: **verified genuine 2026-09-26** — revision `d04171` (8 GB, Sony UK, Pi 5 Rev 1.1), 7.8 GiB reported, boots Ubuntu 24.04 (kernel 6.8.0-1064-raspi). 8 GB doubles the 4 GB minimum — welcome DSP headroom |
| Arducam IMX462 color 141° (stereo pair), **SKU B0444 — Pivariety** | 2 | Amazon (UCTRONICS) | 96 | 95.98 | received | 47.99 ea. Parallel mount, one rigid plate, software sync. Camera connector is **22-pin 0.5 mm**; ships with 22↔22 Type B cables — plugs into the Pi 5 directly. **Baseline is 74 mm** — set by the 6" bore and the measured 71.9 dome flange, not chosen (`housing-layout.md`). **Both verified on the Pi 5 (2026-09-26):** Pivariety driver binds on stock Ubuntu 24.04 and both stream raw 1080p (ADR-017 evidence) |
| SupremeTech 2" acrylic dome, 3/8" flange (radial width; 2.0 thick) | 2 | Amazon (Supreme Tech) | 21 | 21.38 | received | 10.69 ea, pre-drilled flanges. No spares ordered — handle gently; check apex optical uniformity on arrival |
| 8BitDo Ultimate Mobile controller | 1 | Amazon (8BitDo) | — | 49.99 | received | Hall sticks. Telescopic phone-grip, Bluetooth/Android only — the field controller for Cockpit. **No wired USB / PC mode**: bench SITL needs a separate pad or keyboard |
| Gebildet PG7 ×30 + PG9 ×20 cable glands | 1 | Amazon (Gebildet) | 10 | 9.99 | received | Package marked E271 — PG7/PG9 count not yet checked. Penetrators: gland + epoxy back-fill, solder-blob every conductor mid-pot (prior-art.md) |
| Anker 10,000 mAh PowerIQ USB-C power bank | 2 | Amazon (AnkerDirect) | — | 45.99 | received | Two arrived (2-pack at $45.99). Topside: runs the Opal ~10 h. Bench-qualify: router on it one hour, no blinks |
| GL.iNet GL-SFT1200 Opal router | 1 | Amazon (GL Tech) | 40 | 39.99 | received | Topside AP. Configure LAN 192.168.2.0/24; 5 GHz AP so the BT gamepad keeps 2.4 GHz |
| Loctite Marine Epoxy 0.85 oz syringe | 2 | Amazon | 15 | 15.00 | received | Arriving Sunday. ~50 ml total — enough for ~8–12 gland back-fills; buy more before doing all penetrators in one session |
| Amass XT60 pairs w/ 14 AWG 100 mm pigtails | 2 pk | Amazon (Hiteuoms) | 10 | 17.98 | received | **3 pairs per pack** ("6PCS" = pieces) — 6 pairs total, exactly one per ESC drop, **zero spares**. See spare XT60 row below. Female on the source side |
| SanDisk 256 GB Ultra microSDXC + adapter | 1 | Amazon (First Choice Online) | 12 | 56.00 | received | NAND-crisis pricing. Pi boot/rescue + interim bench recording. Third-party seller — **verified genuine 2026-09-26** (`f3probe --destructive` on the EeePC reader: "the device is the real thing") |
| Marine-grade adhesive heat-shrink kit, 4:1 | 1 | Amazon (LONGBIN) | 8 | 8.99 | received | Adhesive-lined = the right kind for wet-adjacent joints |
| 10 AWG silicone wire, 5 ft red + 5 ft black | 1 | Amazon (Kenhihi) | 15 | 8.98 | received | Pack → star point runs |
| Cordless USB-C soldering iron | 1 | Amazon (AutoFittings) | — | 28.99 | received | Fine for signal wiring; 10 AWG + XT90 cups need more heat — have a ≥60 W mains iron for the big joints |
| Cat6 outdoor direct-burial, 100 ft, **CCA** | 1 | Amazon (FYRIKTB) | 25 | 21.99 | received | Tether stock: two ~50 ft tethers incl. spare. CCA fatigues under flex — gentle bends, hard strain relief, treat as consumable. Data-only at this length: fine |
| 14 AWG silicone wire, 2-core, 25 ft | 1 | Amazon (Haerkn) | 10 | 19.98 | received | Distribution → ESC runs; 2-core = paired +/− pulls |
| FEICHAO 35 V 1000 µF XT60 cap filters ×4 | 1 | Amazon (FEICHAO) | 15 | 39.96 | received | **Arrives Sept 8–16** (China lead time). 4,000 µF total at the star point. Bench Phases 1–3 can run without them — short bench leads = low inductance — but install before sealed integration; Castle CapPack is the local fallback if the housing outpaces the mail |
| LiPo safe pouches, 185×75×60 mm ×2 | 1 | Amazon (CNDHDOK) | 12 | 9.99 | received | One pouch per pack — isolation during storage and charging. Arrives with the batteries |
| BX100 cell checkers w/ LV buzzer ×2 | 1 | Amazon (SpeedyFPV) | 8 | 9.49 | received | Arrives Saturday — Friday's first charge relies on the charger's own per-cell display. Plug-read-unplug; standby drain unbalances packs left connected |
| BOJACK MIDI 80 A fuses ×3 + holders ×2 | 1 | Amazon (BOJACK) | 15 | 21.98 | received | **4 fuses arrived** (listing said ×3), 2 holders. Main fuse at the star point (review B1) + two spare elements and a spare holder — field-box spares covered |
| IP68 RJ45 panel-mount coupler, F-F ×2 | 1 | Amazon | — | 15.99 | received | Topside dry box wall only — splash-rated, **never submerged** (prior-art: IP67/68 couplers are not pressure-rated). Second is the spare |
| Tomotato transparent waterproof dry box | 1 | Amazon | 20 | 17.99 | received | **Too small** for the Opal + power bank — needs a bigger box (return or repurpose this one). Topside station: Opal + power bank; tether enters via PG9 gland or the panel coupler. Confirm it floats loaded; leash to kayak |
| Hand vacuum pump / brake bleeder kit w/ gauge | 1 | Amazon (Pathfinder Auto) | 35 | 19.89 | received | The pre-dive leak-test tool: **15 inHg** via the Schrader stem (core out), watch for a steady needle. Check kit for a Schrader adapter; verify pump holds vacuum dead-headed on arrival |
| JST-GH ↔ DF13 adapter board, 4-pin | 1 | Blue Robotics | 10 | 13.44 | received | 2026-09-26. Incl. $1.44 tariff surcharge. Board plus 100 mm DF13↔DF13 and GH↔GH cables — Bar30 → Pixhawk I2C with the pinout guaranteed. Unblocks the Phase 1 depth check |
| SOS Leak Sensor | 1 | Blue Robotics | 5 | 35.00 | received | 2026-09-26, same order ($6.50 shipping). Replaces the bare-wire probe: four sponge-tipped probes (2×6", 2×12") + 4 spare tips — needs liquid, not condensate. 3-pin 0.1" out straight to a Pixhawk AUX pin, ArduSub-native, `FS_LEAK = surface`. **Needs 3.3–5 V on the servo rail** — one ESC BEC (U2 BEC still unconfirmed) or a separate 5 V feed |
| uxcell FFC 22-pin 0.5 mm **Type B**, 500 mm, 5 pcs | 1 | Amazon (uxcell) | 7 | 6.47 | received | 2026-09-26, arriving Tue 2026-09-29. Bench, mock-up and fixture cables plus spares — generous enough to connect cameras without fighting for slack. Plain unshielded FFC: the vehicle gets the shortest length that reaches once the sled/bay order is drawn (pending row below) |
| Raspberry Pi 5 Active Cooler (official) | 1 | Amazon (UeeKKoo, 3rd party) | — | 10.95 | received | 2026-09-27, arriving 2026-09-28. ~$5 list — third-party premium, so check it is genuine on arrival. The bench numbers in ADR-015 were all **uncooled**; re-run them with it. Moves SoC heat into the hull air, not out of the hull — pairs with an air-stirring fan or a conduction path (`sled.md`). Clears the M.2 HAT+ (its standoffs are sized for it). Push-pins and pad are one-use-ish: fit it once. Confirm fan speed control works under Ubuntu, not just RPi OS |
| iRasptek 27 W 5.1 V / 5 A USB-C PD supply | 1 | Amazon (iRasptek) | — | 10.99 | received | 2026-09-27, arriving 2026-09-28. **Bench only** — the vehicle Pi runs from the Pololu off the hotel pack. Fixes the undervoltage the Pi hit on a 4.9 V supply during the build (ADR-017); 5 A lets the Pi 5 run USB peripherals at full current |

**Ordered subtotal: est ~$1,237 (+6 unestimated adds) · paid $1,782.33
(Amazon orders through 2026-08-20 + RobotShop $140.69 + $168.74 incl.
shipping + Blue Robotics $54.94 incl. shipping + uxcell cables $6.47,
2026-09-26 + Active Cooler and bench PSU $21.94, 2026-09-27 — per-order
figures in git history).**

## Core, pending

| Item | Qty | Source | Est $ | Paid $ | Status | Notes |
|---|---|---|---|---|---|---|
| M.2 HAT+ | 1 | | 20 | | pending | |
| NVMe 512 GB–1 TB | 1 | | 70–160 | | pending | Thermal path to hull wall required. NAND-crisis pricing: ~$105/TB best case as of Aug 2026, relief not expected before 2027. 512 GB (~$70) still holds a week of dive days — capacity was never the constraint (ADR-016). Not needed until thermal soak / sealed integration; bench bring-up runs on microSD |
| PVC pipe, caps, o-rings | — | | 60–120 | | pending | **Diameter not settled — do not buy.** `housing-layout.md` leans 6" sched-40 over 4"; gated on the caliper measurements. 6" pipe and caps run ~$40–60 over 4". **Caps → lids (proposal 2026-09-27):** two 3/4" cast acrylic 8 × 8 squares (~$40 each, Falken or Source One), four M6 tie rods, pipe-end O-ring (AS568 2-series, ~6.2" ID) + spares — ~$100 for the closure alone, so this line likely needs raising (`housing-layout.md`, "Endcaps") |
| Hollow polypro rope + closed-cell foam floats for tether | 1 | | 10 | | pending | Cable ordered (Cat6 burial). Rope is the strength member (SV Seeker method); foam bits zip-tied every 1–2 m near the ROV. Seal cable cut ends |
| HDPE frame stock, ballast | — | | 30 | | pending | |
| External I2C compass module | 1 | | 15–30 | | pending | Review 1 M3 / review 2 carry-forward: internal compass sits in ESC field; mount external, away from power wiring, MagFit calibrate in Phase 3/5 |

**Core pending subtotal (est): ~$205–310** depending on NVMe capacity

## Small parts and consumables, pending

Previously mentioned in notes but never costed as line items.

| Item | Qty | Source | Est $ | Paid $ | Status | Notes |
|---|---|---|---|---|---|---|
| DF13 pigtails, 4-pin | set | | 0–10 | | pending | The Bar30 mismatch (JST-GH lead vs DF13 I2C port, confirmed 2026-09-26) is solved by the Blue Robotics adapter in Ordered. Buy DF13 pigtails only if another Pixhawk port needs one — check the Radiolink box first |
| Schrader valve stem + core tool | 1 | | 8 | | pending | **NOT yet ordered.** One fitting, three jobs: pressure test (bike pump, core in), vacuum test (bleeder pump, core out — check the kit for a Schrader adapter), LiPo relief/equalization. Auto-parts store |
| Thermal pads / gap filler | — | | 12 | | pending | NVMe, converters, ESCs to hull wall |
| MicroSD 16–32 GB for Pixhawk, FAT32 | 1 | | 7 | | pending | Only if the Radiolink box card is junk — FMUv2 likes small plain cards |
| Spare o-rings, every size | kit | | 15 | | pending | **Before first assembly.** A nicked o-ring on a Sunday ends the day |
| Silicone grease | 1 | | 12 | | pending | **Molykote 111 or Super Lube only.** Petroleum products attack Buna-N |
| Indicating silica desiccant packs | — | | 5 | | pending | Cave Pearl recipe; oversize for a Pi 5 sweating in a cold lake |
| Spare 2" acrylic dome | 1 | | 11 | | pending | Review 2 minor 5: single-seller part, "handle gently" — a cracked dome mid-season ends the mission |
| Spare XT90-S male connector | 1 | | 8 | | pending | Review 2 MA3: anti-spark resistor is a consumable (~30–50 matings); lives in the field box |
| Spare XT60 pigtail pairs | 2–3 pr | | 8 | | pending | The two packs came as 3 pairs each — 6 pairs for 6 ESC drops, none spare. A melted or mis-soldered one otherwise stops a thruster |
| Pi 5 camera cables, 22↔22-pin, 0.5 mm, **Type B**, vehicle length | 2+2 | | 12 | | pending | **Not blocking the bench test** — the Arducams have 22-pin connectors and shipped with 22↔22 Type B cables (~150 mm) that plug straight into the Pi 5. Needed for the vehicle only, **length from the CAD cable path once the sled and bay order are drawn** — with cameras and Pi both on the sled, Pi right behind the cameras (`sled.md`), the stock ~150 mm cables may reach and this row may not be needed at all; the 500 mm uxcell set (Ordered) covers bench work meanwhile. Match Type B — wrong type makes no contact; never flip one to make it fit. Shortest that reaches; route away from ESC leads |
| ApisQueen ESC tuning tool | 1 | | 12–15 | | pending | **Hold — compatibility unconfirmed.** O'Hara card = boat ESC line; Feather USB board = 80–300 A standalone ESCs; unclear which (if either) programs the U2's integrated ESC. Check the manual on arrival or email help@underwaterthruster.com. Only needed if depth hold is jerky and ArduSub deadzone params can't fix it |

**Small parts subtotal (est): ~$115**

## Field / mission gear, pending

| Item | Qty | Source | Est $ | Paid $ | Status | Notes |
|---|---|---|---|---|---|---|
| Downline: weighted marker, line, small surface float | 1 | | 25 | | pending | The primary navigation datum (navigation.md Method 1) |
| Quick-releases / carabiners | 2 | | 10 | | pending | Tether and rode, **both to the boat, neither to the body** |
| Milk crate for tether flake | 1 | | 0 | | pending | Probably free |
| Drift sock | 1 | | 20 | | pending | Station-keeping at anchor; optional |

**Field gear subtotal (est): ~$55**

## Likely already owned — confirm

| Item | Have? | Notes |
|---|---|---|
| Multimeter with DC current clamp | ? | Verify actual thruster draw against the 150 W spec without breaking the circuit |
| Joystick / gamepad | ? | Needed for Phase 0 SITL |
| Bike pump | ? | Leak testing |
| Kitchen scale + bucket | ? | Thrust measurement, Phase 2 |
| Topside laptop | ? | QGC + ROS 2 rqt tools |
| Wired/X-input gamepad for bench SITL | ? | The 8BitDo Ultimate Mobile (ordered) is Android-only — desktop QGC/SITL needs any pad the laptop recognizes |
| RJ45 crimper + plugs | ? | Required: tether ends get cut to pass through glands, then re-terminated. CCA strands are brittle — crimp gently, strain-relieve behind the plug |
| Kayak, anchor, rode | ? | The surface platform |

## Options / later

| Item | Est $ | Notes |
|---|---|---|
| Parallel green line lasers | 20 | Scaling **and** altitude for optical flow. Green penetrates turbid water far better than red |
| USB audio interface, 96–192 kHz multichannel | 100–200 | Acoustic ranging. CM6206-class does 96k stereo |
| 27 mm piezo discs + polyurethane | 20 | Transducers. Work far better underwater than they should |
| 12 V LiFePO4 pack | 50 | Hotel only — BMS current limit rules out propulsion |
| Single small diffuse light, potted | 20 | Shadowed-structure inspection; required for deeper sites (ADR-004) |
| Down/nav camera + optical flow | 100 | Deferred past v1. For ambient ops prefer mono IMX296 + fast CS lens over OV9281 |
| Ethernet switch, small internal | 15 | Only needed if IP/multiple Ethernet cameras return |
| 4" dome port for main housing | 40 | Retired by the twin mini-dome camera pods (ADR-003/015); revisit if a high-res camera goes in the main tube |
| VESC (single) | 60–100 | Vertical axis only. FOC gives smooth control through zero |
| Surface buoy: float, GNSS, WiFi/LoRa | ? | ADR-009's preferred architecture; not yet scoped |

## Deliberately not buying

| Item | Why |
|---|---|
| Blue Robotics Navigator | ADR-008 |
| Fathom-X tether interface | Unnecessary under ~50 m; saves ~$100 |
| Echosounder for altitude hold | Blows budget; lasers + optical flow substitute |
| XT60 on the main power path | 60 A rated vs ~61 A peak. Thermal bottleneck in a sealed tube |

## Shop tooling (household tools — excluded from build totals)

Bought because CARP needs printed brackets/mounts, but it's a general shop
tool serving other projects too, so it doesn't count against the vehicle cost.

| Item | Qty | Source | Paid $ | Status | Notes |
|---|---|---|---|---|---|
| Elegoo Centauri Carbon 2 Combo | 1 | Amazon (ELEGOO Official US) | 378.61 | received · **validated 2026-08-30** | Enclosed CoreXY, 256 mm³, 350 °C hardened nozzle, HEPA+carbon filter; Combo = CANVAS multi-color unit included. First part: a bench holder for the Pi 5, Onshape → slice → print, no trouble on the machine side |
| ELEGOO PLA+ 1.75 mm, pink & purple 2 kg | 1 | Amazon (ELEGOO Official US) | 28.99 | received | 2 spools. Toys / learning / doll wheelchair |
| ELEGOO PETG 1.75 mm, yellow & orange 2 kg | 1 | Amazon (ELEGOO Official US) | 26.58 | received | 2 spools. Wet-environment parts; high-vis colors are a feature underwater |
| ELEGOO PLA+ 1.75 mm, white 1 kg | 1 | Amazon (ELEGOO Official US) | 13.24 | received | 1 spool. General purpose |
| Spurtar vernier caliper, 150 mm, steel | 1 | Amazon (Wittyware) | 16.97 | received | The one to trust for dimensions that drive the CAD — flange OD, thruster OD, ESC brick |
| Ultrassist plastic vernier calipers, 150 mm ×2 | 1 | Amazon (Ultrassist) | 6.99 | received | One for Isabelle to learn on. The other kept for the shop: plastic is **non-conductive**, which is the right property for measuring around live LiPo terminals |
| YISHU 6 ft surge-protected power strip, 8 outlets + 4 USB | 1 | Amazon (QINGLIANFENG TECH) | 11.99 | received | 2026-09-27, arriving 2026-09-28. Bench power |

**Shop tooling subtotal: $483.37 · out of pocket $407.32** (rewards points −$76.05)

Still pending for the print shop: **ASA 1 kg** (~$20 — exterior ROV brackets,
UV-stable; needs the enclosure + ventilation), desiccant/dry bags for
filament storage (shared line with the housing desiccant).

All 5 spools received (2 PLA+ colored, 2 PETG, 1 PLA+ white) — the filament
order is complete. Only ASA remains unbought, and it is not needed until
exterior brackets.

**Caliper range is 150 mm, and two dimensions that matter exceed it:** the
YOWOO pack at 155 long and the 6" bore at 154.1. Use a steel rule for those
two. Everything else on the `housing-layout.md` measurement list — thruster
OD and length, ESC brick, dome flange OD — falls inside 150.

**CAD is Onshape.** The toolchain is proven end to end as of 2026-08-30;
the only friction was re-learning the tool, not the machine. Design parts
with driving variables (tube ID, flange diameter, stereo baseline) so the
housing layout can be swept rather than argued — see `open-questions.md`.

Printed parts are brackets and mounts only — **never the pressure boundary**
(FDM layer bonds are not watertight; housing stays PVC/acrylic/epoxy).

**Material rule for printed parts:**

- **PLA+ — bench and mock-up only.** Fit checks, holders, jigs, anything that
  lives on a table at room temperature. It softens around 55–60 °C, and the
  sealed hull is deliberately a warm place (Pi 5 and NVMe both thermal-padded
  to the hull wall) before the sun gets to a dark tube on a kayak deck.
- **PETG — inside the hull.** Anything structural that ships in the vehicle.
- **ASA — outside the hull.** UV-stable; still pending purchase.

A part proven in PLA+ on the bench is a finished *design*, not a finished
part: reprint it in PETG or ASA before it goes in the build.

## Running totals

| | Est $ | Paid $ |
|---|---|---|
| Ordered | ~1,237 | 1,782.33 |
| Core pending | ~205–310 | |
| Small parts pending | ~115 | |
| Field gear pending | ~55 | |
| **Paid + pending (6 thrusters, no options)** | **~$2,155–2,260** | |
| Shop tooling (excluded from above) | | 407.32 out of pocket (483.37 list) |

Confirms `open-questions.md`: this is not a $500 build — it is a ~$2,000
build (≈4×). The projection is Paid ($1,782.33, a known number) plus pending
estimates ($375–480); ordered items ran ~25% over their estimates, so pending
items may too. (Corrected 2026-08-20 per design review M1 — the earlier
"$1,550–1,700" summary mixed estimates for items whose real prices were
already known. Pending re-totaled after review 2 added the compass, spare
dome, and spare XT90-S.)

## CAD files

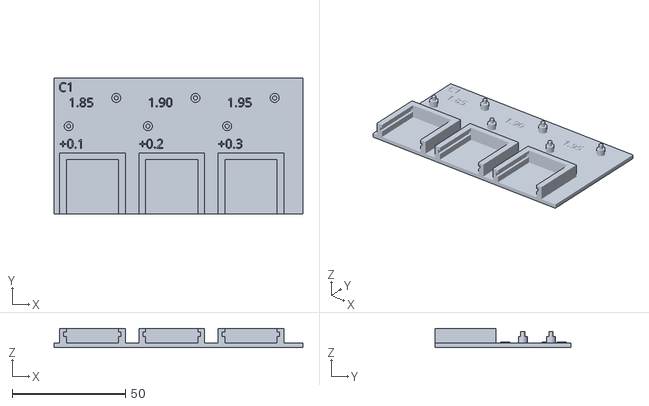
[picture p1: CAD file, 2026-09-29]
cad/prints/coupon_a_c1.stl
110.0 x 60.0 x 8.50

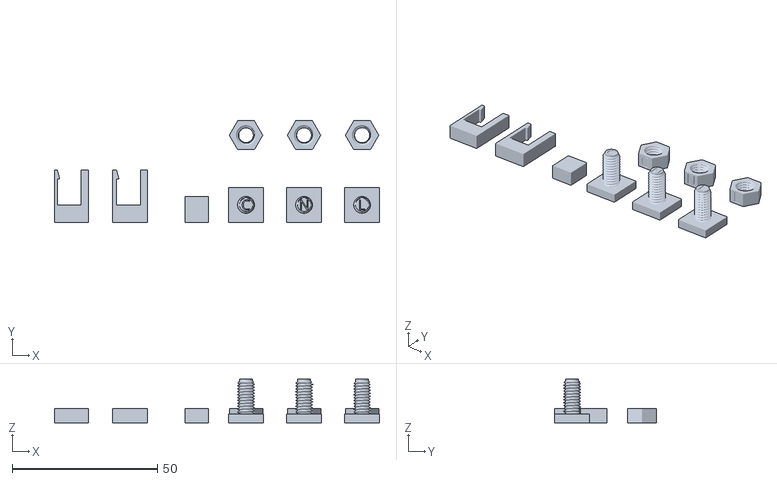
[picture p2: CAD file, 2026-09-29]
cad/prints/coupon_b1.stl
112.0 x 35.0 x 15.0

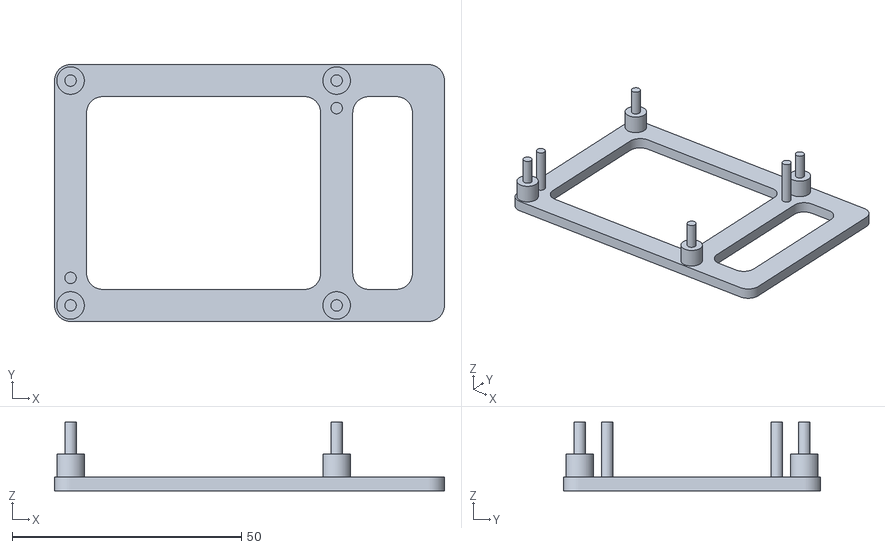
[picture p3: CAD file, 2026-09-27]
cad/prints/pi_bracket.stl
85.0 x 56.0 x 15.0

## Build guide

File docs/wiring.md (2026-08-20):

# Wiring Plan — v1 Baseline

Single battery per dive (the second pack is the swap spare, ADR-013); the
propulsion/hotel split (ADR-014) stays deferred until there's a reason.

## Power tree

```mermaid
flowchart TD
    B["4S LiPo 6000 mAh<br/>(XT90-S on pack lead)"] -->|XT90-S = service disconnect<br/>10 AWG| D["Distribution star point<br/>+ bulk capacitors"]
    D -->|14 AWG, XT60 ×6<br/>female on source side| E1["U2 ESC/thruster 1–6"]
    D -->|spur| PM["Pixhawk power module<br/>(voltage sense + 5.3 V)"]
    PM --> PX["Pixhawk POWER port"]
    D -->|12–17 V in| POL["Pololu D36V50F5<br/>5 V @ 5.5 A"]
    POL -->|5 V, GPIO header| PI["Pi 5"]
```

## Signal / data

```mermaid
flowchart LR
    PX["Pixhawk"] -->|"PWM signal+GND ×6<br/>MAIN OUT 1–6"| ESC["U2 ESCs"]
    BAR["Bar30"] -->|"I2C (BARO_EXT_BUS)"| PX
    PX <-->|USB| PI["Pi 5"]
    CAM1["IMX462 L"] -->|CSI ribbon| PI
    CAM2["IMX462 R"] -->|CSI ribbon| PI
    PI <-->|"Ethernet, RJ45 crimped dry-side<br/>of the tether gland"| TETHER["~15 m Cat6 tether (CCA)"]
    TETHER <--> OPAL["Opal router (topside)<br/>LAN 192.168.2.0/24"]
    OPAL -.->|WiFi 5 GHz| PHONE["Phone: Cockpit<br/>+ 8BitDo via BT 2.4 GHz"]
    BANK["Anker 10k power bank"] -->|USB-C 5 V| OPAL
```

## The rules (each one bought with someone's misery — see prior-art.md)

0. **Main fuse (MIDI/ANL 80 A) on the pack lead at the star point.** The
   pack delivers ≥120 A into a dead short inside a tube nobody can open
   mid-dive; the XT90-S is inrush management, not protection. Optionally
   15 A blade fuses per ESC drop. (Design review B1.)
1. **XT90-S is the service disconnect.** The pre-charge resistor lives in the
   male pin — never bury it behind a permanent adapter and disconnect
   elsewhere. Charging uses the XT90M→XT60F adapter, outside the vehicle.
   **The anti-spark element is a consumable** (~30–50 matings before the
   resistor degrades and it becomes a plain XT90; failure is silent — review 2
   MA3). Inspect the male pin for pitting every ~10 dives, carry the spare
   male from the field box, and remember it's the only inrush protection
   ahead of an 80 A fuse and a 6 Ah pack.
2. **Star-point grounding.** Pack negative to one heavy point; Pi and Pixhawk
   grounds taken from that point *directly*, never daisy-chained off an ESC
   return. 56 A through a shared return shifts ground under load → phantom
   thruster twitches.
3. **ESC signal grounds return to the Pixhawk servo rail** alongside their
   signals.
4. **At most one ESC BEC 5 V line lands on the servo rail** (the U2 150 W
   variant has a 5 V/1 A BEC). Six paralleled BECs fight. Snip or tape back
   the rest — signal and ground only.
5. **Never backfeed 5 V into the Pixhawk through the servo rail.** The
   Pixhawk eats from its power module; the Pi eats from the Pololu. Separate
   rails, by design (power-budget.md).
6. **Pi powered via GPIO header** from the Pololu → set
   `usb_max_current_enable=1` or USB devices get capped at 600 mA.
7. **Bulk capacitance at the star point** — six thrusters slamming reverse
   sags the bus; brownout reboots are the classic cheap-build field failure.
8. **CSI ribbons route away from ESC power leads** — documented EMI failure
   mode (camera vanishes, corrupted frames). Ferrite/foil if it appears.
9. **Solder, then heat-shrink, every joint** — bullet connectors corrode;
   inside penetrators every conductor gets a stripped solder blob mid-pot.
10. **Leak probe at the hull low point → Pixhawk AUX pin**, `LEAK1_PIN` set,
    `FS_LEAK = surface`. Auto-surface-on-leak is the cheapest insurance in
    the project; mount above the condensate sweat line and bench-trip it.

## Open decision: power module placement

The Radiolink power module has XT60 connectors, and the main path peaks at
~56 A with 6 thrusters — right at the XT60's limit, which the BOM explicitly
bans on the main path. Two options:

- **A (chosen for v1): power module on a spur** off the star point. Pixhawk
  gets clean 5.3 V and accurate *voltage* telemetry; current telemetry reads
  only the Pixhawk's own draw, so set `BATT_MONITOR` for voltage-only and
  don't trust the mAh counter. Voltage sag under load is still visible —
  which is the number that actually predicts a brownout.
- **B (later, if current telemetry is wanted): re-terminate the module with
  XT90s** or add a standalone hall-effect sensor on the main path.

## Bench-phase deltas

- Phase 1–2 run without the Pololu/Pi: Pixhawk on USB power bank, servo
  tester fed by a USB charger or one ESC BEC.
- Thruster tests always on the LiPo, never a bank or BEC.
- Verify star-point integrity with a meter under load (Phase 3 checklist).

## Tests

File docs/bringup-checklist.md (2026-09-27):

# Bring-Up Checklist

Order matters. Every item below happens **before** anything is potted, sealed,
or epoxied.

## Phase 0 — Before hardware arrives

- [ ] ArduSub in SITL
- [ ] Frame type selected and confirmed in simulation
- [ ] Joystick/gamepad mapping worked out
- [ ] Verify axis signs in sim — sign errors are cheap here and expensive in a pond
- [ ] **Camera geometry + housing layout on paper — before any pipe is bought**
      (review 2 MA2). Drawn: see `housing-layout.md` — 6" single housing,
      74 mm stereo baseline (set by the bore and the 71.9 flange, not chosen). Confirm the
      five assumed dimensions in that file before any pipe is cut
- [x] ADR-017 stack confirmed by the CSI/encode bench prototype (dual capture
      → encode → rosbag on the Pi) before Phase 3 integration. **Done
      2026-09-26 on Ubuntu (B1)**: 1080p10 with software stereo sync
      (~23 µs); 1080p30 does not fit (ADR-015). The phone
      stream is left out on purpose: it is a tether/topside question, covered
      by the iperf3 and topside-qualification items in Phase 3
- [x] **Print toolchain validated** (2026-08-30) — Onshape → slice → Centauri
      Carbon 2, first part a bench holder for the Pi 5 in PLA+. Bracket and
      mount design is unblocked; carry designs forward but reprint in PETG
      (inside the hull) or ASA (outside) per the material rule in `bom.md`

## Phase 1 — Autopilot acceptance (within the return window)

Run the day it arrives. A bad board goes back inside the window.

- [x] Flash ArduSub, confirm boot, QGC connects (2026-09-26 — `Pixhawk1-1M` ArduSub **4.7.1** (git `dbe79216`) via QGC 5.1.4 custom firmware from Windows, then reflashed to the full **`Pixhawk1`** build once the board reported 2 MB flash (ADR-008); boots to MANUAL, attitude and compass heading respond. Onboard sensors reported: IST8310 compass (I2C0), MS5611 baro (SPI1))
- [x] IMU noise on a still bench — obvious spikes or drift means return it
      *(2026-09-26: accel calibrated — offsets X 0.01 / Y −0.30 / Z 1.26 m/s²,
      scales within 0.5% of 1. Only **one IMU** detected: MPU6000 on SPI,
      `INS_ACC2_ID = 0`. A genuine Pixhawk1 carries a second (LSM303D +
      L3GD20) — missing on this Radiolink board, or not in the 1 MB build?
      ArduSub runs fine on one.)*
      *Still-bench log (344 s, board level and untouched): gyro sd
      0.03 °/s, bias steady to 0.0002 rad/s start to end; accel sd
      1.3–1.5 mg, |g| = 9.75 m/s². Pass. Full `Pixhawk1` build (39 s)
      matches. Still one IMU on the full build.*
- [ ] Power module holds 5 V under a couple of amps
- [ ] Calibrate `BATT_VOLT_MULT` against a meter (Radiolink units are known to read low)
- [ ] MS5837 on I2C, set `BARO_EXT_BUS`, confirm depth reads
- [ ] Confirm reported baro device type — 0x12 for 30BA, 0x18 for 02BA. Misidentification fails *silently* with plausible wrong depth
- [x] SD card write and read (2026-09-26 — `LOG_DISARMED=1`; two logs written, downloaded over USB via QGC, parsed cleanly)
- [ ] Exercise all PWM outputs against servo or scope
- [x] `BRD_SAFETY_DEFLT = 0` (ADR-007; named `BRD_SAFETYENABLE` before ArduSub 4.7) — already the 4.7.1 default, confirmed in `params/carp-bench-2026-09-26.params`

## Phase 2 — Thruster acceptance

Per unit, on the servo tester, no autopilot involved.

- [ ] **Set the tester pot to centre before applying power.** It boots into
      manual mode following knob position, *not* 1500 µs
- [ ] **Clamp the thruster down.** Bidirectional units jump on connect
- [ ] Check which U2 variant arrived and whether its ESC has a BEC (the
      150 W variant ships one, 5 V/1 A). If yes it can feed the tester; if
      not, any USB charger or bench supply works
- [ ] If ESCs have BECs: plan the servo-rail wiring so at most one BEC's 5 V
      line lands on the rail — six paralleled BECs fight
- [ ] Confirm rotation direction, sort CW/CCW pairs before mounting
- [ ] Find true neutral and map deadband width (tester resolves 2 µs)
- [ ] Verify bidirectional behaviour across 1000–2000 µs
- [ ] Bucket + kitchen scale: measure **actual** thrust both directions at known
      pulse widths. Specs are consistently optimistic
- [ ] 20 min continuous run, hand on the can, note temperature
- [ ] Clamp-meter the current draw against the 150 W spec
- [ ] All four/six simultaneously — combined draw against the pack

## Phase 3 — Integration, still dry

- [ ] Pixhawk → ESCs, wired to the frame diagram's output numbering
- [ ] Common ground between ESC power and signal — floating grounds produce
      phantom twitches
- [ ] Star-point grounding verified with a meter under load
- [ ] `MOT_n_DIRECTION` corrections rather than rewiring
- [ ] Servo tester inline between Pixhawk and one ESC — read what ArduSub is
      actually commanding
- [ ] Pi 5 boots, NVMe mounts, `usb_max_current_enable=1` set
- [ ] Cameras stream, encode, and record to NVMe
- [ ] rosbag records with keyframe interval 1–2 s, decodes and scrubs on
      playback (`image_transport republish ffmpeg raw`, or the operator-station
      rqt tools)
- [ ] Thermal soak — everything running, **45 min** (review 1 minor 10; 30 was
      a transcription drift), check converter and NVMe temps
- [ ] Measure the real tether link: iperf3 through the actual CCA Cat6 + Opal.
      Record the negotiated rate — the ADR-016 offload plan depends on it —
      and sum the operating load (2× video + MAVLink + ROS topics) against it
- [ ] Topside qualification: router in the dry box on bank power, phone at
      operating distance, Cockpit + gamepad running ~30 min under motion —
      confirm no WiFi dropout (review 2 minor 7)

## Phase 4 — Housing

- [ ] Vacuum test via Schrader stem (core out): **15 inHg** (≈5.2 m — the
      site depth; 10 inHg only proves 3.5 m), steady needle for a minute,
      housing **empty**
- [ ] Main fuse installed at the star point and verified (see wiring.md)
- [ ] Leak probe at the low point wired to Pixhawk AUX; `FS_LEAK = surface`
      set and bench-tripped
- [ ] If it fails: 2–3 psi from a bike pump (core in) + soapy water on every
      joint to find the leak, then re-test under vacuum
- [ ] Leak test again with a paper towel inside and nothing valuable
- [ ] Relief/vent path confirmed: Schrader stem, core in for diving; verify
      the core tool cracks it and **always vent before opening the lid**
      (ADR-013)
- [ ] Thermal paths: NVMe, converters, and ESCs padded to the hull wall
- [ ] Internal baro logged as a leak detector — rising internal pressure means
      water displacing air
- [ ] Spare o-rings on hand before first close-up

## Phase 5 — First water

- [ ] Ballast to slightly positive (ADR-002)
- [ ] Tether quick-release to a deck cleat, **never to your body**
- [ ] Confirm it surfaces on power-off
- [ ] Depth hold, shallow
- [ ] All axes on the joystick, confirm signs match expectation
- [ ] Full dive on one pack, log actual endurance against the ~110 W
      no-lights estimate (~39 min to 20% reserve)
- [ ] **Snag drill** (review 2 / ADR-009): with the real rigging, gentle
      haul-test from multiple bearings; practice slack-and-drive; confirm the
      buoy-and-return kit is aboard. A protocol never rehearsed isn't one
- [ ] Run the whole day from `field-checklist.md` — shake it down while the
      stakes are low

## Deferred until it swims

- `udp_bridge` and Project11 operator station
- Optical flow
- Acoustic ranging

Both of the latter are projects in their own right and neither blocks
inspecting a contact.

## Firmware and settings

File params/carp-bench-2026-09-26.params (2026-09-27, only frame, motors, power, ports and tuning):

1	1	ATC_ANGLE_BOOST	1	2
1	1	ATC_ANGLE_MAX	3e+01	9
1	1	ATC_ANG_LIM_TC	1	9
1	1	ATC_ANG_PIT_P	6	9
1	1	ATC_ANG_RLL_P	6	9
1	1	ATC_ANG_YAW_P	6	9
1	1	ATC_RATE_FF_ENAB	1	2
1	1	ATC_RATE_P_MAX	0	9
1	1	ATC_RATE_R_MAX	0	9
1	1	ATC_RATE_WPY_MAX	6e+01	9
1	1	ATC_RATE_Y_MAX	1.8e+02	9
1	1	ATC_RAT_PIT_D	0.0036	9
1	1	ATC_RAT_PIT_D_FF	0	9
1	1	ATC_RAT_PIT_FF	0	9
1	1	ATC_RAT_PIT_FLTD	3e+01	9
1	1	ATC_RAT_PIT_FLTE	0	9
1	1	ATC_RAT_PIT_FLTT	3e+01	9
1	1	ATC_RAT_PIT_I	0.09	9
1	1	ATC_RAT_PIT_IMAX	0.444	9
1	1	ATC_RAT_PIT_NEF	0	2
1	1	ATC_RAT_PIT_NTF	0	2
1	1	ATC_RAT_PIT_P	0.135	9
1	1	ATC_RAT_PIT_PDMX	0	9
1	1	ATC_RAT_PIT_SMAX	0	9
1	1	ATC_RAT_RLL_D	0.0036	9
1	1	ATC_RAT_RLL_D_FF	0	9
1	1	ATC_RAT_RLL_FF	0	9
1	1	ATC_RAT_RLL_FLTD	3e+01	9
1	1	ATC_RAT_RLL_FLTE	0	9
1	1	ATC_RAT_RLL_FLTT	3e+01	9
1	1	ATC_RAT_RLL_I	0.09	9
1	1	ATC_RAT_RLL_IMAX	0.444	9
1	1	ATC_RAT_RLL_NEF	0	2
1	1	ATC_RAT_RLL_NTF	0	2
1	1	ATC_RAT_RLL_P	0.135	9
1	1	ATC_RAT_RLL_PDMX	0	9
1	1	ATC_RAT_RLL_SMAX	0	9
1	1	ATC_RAT_YAW_D	0	9
1	1	ATC_RAT_YAW_D_FF	0	9
1	1	ATC_RAT_YAW_FF	0	9
1	1	ATC_RAT_YAW_FLTD	5	9
1	1	ATC_RAT_YAW_FLTE	0	9
1	1	ATC_RAT_YAW_FLTT	5	9
1	1	ATC_RAT_YAW_I	0.018	9
1	1	ATC_RAT_YAW_IMAX	0.222	9
1	1	ATC_RAT_YAW_NEF	0	2
1	1	ATC_RAT_YAW_NTF	0	2
1	1	ATC_RAT_YAW_P	0.18	9
1	1	ATC_RAT_YAW_PDMX	0	9
1	1	ATC_RAT_YAW_SMAX	0	9
1	1	BATT2_MONITOR	0	2
1	1	BATT3_MONITOR	0	2
1	1	BATT4_MONITOR	0	2
1	1	BATT5_MONITOR	0	2
1	1	BATT6_MONITOR	0	2
1	1	BATT7_MONITOR	0	2
1	1	BATT8_MONITOR	0	2
1	1	BATT9_MONITOR	0	2
1	1	BATT_MONITOR	0	2
1	1	FLTMODE1	19	2
1	1	FLTMODE2	19	2
1	1	FLTMODE3	0	2
1	1	FLTMODE4	0	2
1	1	FLTMODE5	9	2
1	1	FLTMODE6	9	2
1	1	FLTMODE_CH	0	2
1	1	FRAME_CONFIG	1	2
1	1	INS_GYRO_FILTER	20	4
1	1	INS_HNTCH_ENABLE	0	2
1	1	MOT_10_DIRECTION	1	2
1	1	MOT_11_DIRECTION	1	2
1	1	MOT_12_DIRECTION	1	2
1	1	MOT_1_DIRECTION	1	2
1	1	MOT_2_DIRECTION	1	2
1	1	MOT_3_DIRECTION	1	2
1	1	MOT_4_DIRECTION	1	2
1	1	MOT_5_DIRECTION	1	2
1	1	MOT_6_DIRECTION	1	2
1	1	MOT_7_DIRECTION	1	2
1	1	MOT_8_DIRECTION	1	2
1	1	MOT_9_DIRECTION	1	2
1	1	MOT_BAT_CURR_MAX	0	9
1	1	MOT_BAT_CURR_TC	5	9
1	1	MOT_BAT_IDX	0	2
1	1	MOT_BAT_VOLT_MAX	0	9
1	1	MOT_BAT_VOLT_MIN	0	9
1	1	MOT_BOOST_SCALE	0	9
1	1	MOT_FV_CPLNG_K	1	9
1	1	MOT_HOVER_LEARN	2	2
1	1	MOT_IDLE_SEC	0	9
1	1	MOT_OPTIONS	0	4
1	1	MOT_PWM_MAX	1900	4
1	1	MOT_PWM_MIN	1100	4
1	1	MOT_PWM_TYPE	0	2
1	1	MOT_SAFE_DISARM	0	2
1	1	MOT_SAFE_TIME	1	9
1	1	MOT_SLEW_DN_TIME	0	9
1	1	MOT_SLEW_UP_TIME	0	9
1	1	MOT_SPIN_ARM	0.1	9
1	1	MOT_SPIN_MAX	0.95	9
1	1	MOT_SPIN_MIN	0.15	9
1	1	MOT_SPOOL_TIME	0.5	9
1	1	MOT_SPOOL_TIM_DN	0	9
1	1	MOT_THST_EXPO	0.65	9
1	1	MOT_THST_HOVER	0.5	9
1	1	MOT_YAW_HEADROOM	200	4
1	1	SERIAL0_BAUD	115	6
1	1	SERIAL0_PROTOCOL	2	2
1	1	SERIAL1_BAUD	57	6
1	1	SERIAL1_OPTIONS	0	6
1	1	SERIAL1_PROTOCOL	2	2
1	1	SERIAL2_BAUD	57	6
1	1	SERIAL2_OPTIONS	0	6
1	1	SERIAL2_PROTOCOL	2	2
1	1	SERIAL3_BAUD	230	6
1	1	SERIAL3_OPTIONS	0	6
1	1	SERIAL3_PROTOCOL	5	2
1	1	SERIAL4_BAUD	230	6
1	1	SERIAL4_OPTIONS	0	6
1	1	SERIAL4_PROTOCOL	5	2
1	1	SERIAL5_BAUD	57	6
1	1	SERIAL5_OPTIONS	0	6
1	1	SERIAL5_PROTOCOL	-1	2
1	1	SERVO1_FUNCTION	33	4
1	1	SERVO1_MAX	1900	4
1	1	SERVO1_MIN	1100	4
1	1	SERVO1_REVERSED	0	2
1	1	SERVO1_TRIM	1500	4
1	1	SERVO2_FUNCTION	34	4
1	1	SERVO2_MAX	1900	4
1	1	SERVO2_MIN	1100	4
1	1	SERVO2_REVERSED	0	2
1	1	SERVO2_TRIM	1500	4
1	1	SERVO3_FUNCTION	35	4
1	1	SERVO3_MAX	1900	4
1	1	SERVO3_MIN	1100	4
1	1	SERVO3_REVERSED	0	2
1	1	SERVO3_TRIM	1500	4
1	1	SERVO4_FUNCTION	36	4
1	1	SERVO4_MAX	1900	4
1	1	SERVO4_MIN	1100	4
1	1	SERVO4_REVERSED	0	2
1	1	SERVO4_TRIM	1500	4
1	1	SERVO5_FUNCTION	37	4
1	1	SERVO5_MAX	1900	4
1	1	SERVO5_MIN	1100	4
1	1	SERVO5_REVERSED	0	2
1	1	SERVO5_TRIM	1500	4
1	1	SERVO6_FUNCTION	38	4
1	1	SERVO6_MAX	1900	4
1	1	SERVO6_MIN	1100	4
1	1	SERVO6_REVERSED	0	2
1	1	SERVO6_TRIM	1500	4
1	1	SERVO7_FUNCTION	0	4
1	1	SERVO7_MAX	1900	4
1	1	SERVO7_MIN	1100	4
1	1	SERVO7_REVERSED	0	2
1	1	SERVO7_TRIM	1500	4
1	1	SERVO8_FUNCTION	0	4
1	1	SERVO8_MAX	1900	4
1	1	SERVO8_MIN	1100	4
1	1	SERVO8_REVERSED	0	2
1	1	SERVO8_TRIM	1500	4
1	1	SERVO9_FUNCTION	181	4
1	1	SERVO9_MAX	1900	4
1	1	SERVO9_MIN	1100	4
1	1	SERVO9_REVERSED	0	2
1	1	SERVO9_TRIM	1500	4

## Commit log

2026-08-20 Procurement day, camera architecture, and prior-art survey
    - bom.md: restructured into a procurement tracker (est/paid/status);
    six orders recorded, $1,239.82 paid; six thrusters ordered resolves
    the 4-vs-6 question by purchase
    - ADR-011/013 committed by purchase; ADR-012 reopened (BlueROV1 frame
    now live with six thrusters); ADR-014 live
    - ADR-004 reversed: ambient light first, no lights on v1; power budget
    drops to ~110 W and endurance gains ~30-40% per pack
    - ADR-015 under revision: stereo pair of Arducam IMX462 141° behind
    twin 2" mini-domes replaces IP cameras; ordered
    - Housing/camera layout coupled into one open question; frame and tube
    dimensions explicitly undecided
    - p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
2026-08-20 Wiring plan, topside control station, and second procurement wave
    - wiring.md: power tree and signal map (mermaid), grounding and BEC
    rules, power-module-on-spur decision (voltage-only telemetry)
    - UBEC deleted: its loads evaporated (lights cut, Bar30 on Pixhawk,
    tester on USB); added the one-BEC-on-the-servo-rail rule
    - Topside settled: Opal router (192.168.2.0/24, 5 GHz), Anker 10k bank,
    8BitDo Ultimate Mobile (field-only - bench SITL needs a wired pad)
    - Orders recorded: $1,563.69 paid across ten orders; all wire gauges,
    glands, epoxy, heat-shrink, XT60s, 256GB microSD, Cat6 tether stock
    (CCA - flagged as flex-consumable), cordless iron
    - Capacitor spec: 35V minimum, 16V RC-car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
2026-08-20 Vacuum-first leak testing, Schrader consolidation, pump ordered
    - ADR-001 and bringup checklist: vacuum test (~10 inHg, core out) is
    the pass/fail gate — it loads seals the way depth does; bike-pump
    positive pressure demoted to leak-localization debug tool
    - One Schrader stem serves pressure test, vacuum port, and LiPo relief
    - Vacuum pump kit ordered ($19.89); paid $1,583.58
    - ESC tuning tool still on hold; U2 bundled ESC family unnamed on the
    product page — check the manual or email ApisQueen
    Claude-Session: https://claude.ai/code/session_017CvrPARnDm8UzNG6NeyaUA
2026-08-20 Design review response: fuse, leak failsafe, snag protocol, honest costs
    - docs/reviews/2026-08-20-design-review.md: independent fresh-agent
    review, findings ranked blocker/major/minor
    - B1 closed: 80A MIDI main fuse at the star point (wiring rule 0, BOM,
    Phase 3 checklist); fuses + holders + spares ordered
    - B2 closed: snag recovery rewritten in ADR-009 - haul-test, slack and
    drive, buoy and return with help; never solo free-dive a fouled line
    - M8: leak probe + FS_LEAK=surface added to wiring, params, checklist
    - M1: cost projection recomputed from Paid + pending: ~$2,000 all-in
    (~4x the original $500); README updated to match
    - M6: endurance figures propagated post-lights (48/39 m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
2026-08-20 Shop tooling: Centauri Carbon 2 Combo and starter filament
    Tracked separately from the vehicle build total — it's a household tool
    that CARP happens to need for brackets and mounts. ASA still pending;
    printed parts never serve as the pressure boundary.
    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
2026-08-20 Respond to second design review (PR #1)
    Closes MA1 (relief path = Schrader stem, named in ADR-013 with vent
    procedure), MA2 (camera/housing layout gated in Phase 0 before pipe),
    MA3 (XT90-S anti-spark wear rule + field spare). Clears the review-1
    carry-forwards: ADR-017 written (leaning vanilla Pi OS over BlueOS),
    external compass on the BOM, 45-min thermal soak, snag drill in Phase 5,
    and a new field-day checklist. Minors: spare dome, tether iperf test,
    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
2026-08-30 Housing layout: 6" single housing drawn, stereo baseline pinned at 75 mm
    Lays out and dimensions the four housing options against the BlueROV1
    frame, closing the "housing diameter and camera mounting — one layout
    problem" entry in open-questions.md. Leaning option B: one 6" sched-40
    tube, ~400 long, envelope 600 x 338 x 295.
    The drawing settled a question the prose could not. Two ~D70 dome
    flanges at 75 mm centres span 145 mm against a 154.1 bore, leaving
    4.5 mm each side; at 85 mm centres they do not fit the bore at all and
    at 100 they exceed even the tube OD. The "~75-100 mm centres" carried
    in open-questions.md and the Phase 0 checklist was never a range — the
    bore pins the stereo ba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
2026-08-30 Calipers ordered; unstale the PVC and camera-baseline rows
    Two vernier calipers, $23.96, arriving 2026-08-31 — the tool the
    housing-layout.md measurement list has been waiting on. The steel
    Spurtar is the one to trust for dimensions that drive the CAD; the
    plastic pair is non-conductive, which is the right property for
    measuring around live LiPo terminals.
    Both are 150 mm, and the two dimensions that matter most exceed it: the
    YOWOO pack at 155 long and the 6" bore at 154.1. Steel rule for those.
    Everything else on the list — thruster OD and length, ESC brick, dome
    flange OD — falls inside 150.
    Also corrected two rows the housing work left stale: the core-pending
    PVC line still said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
2026-09-26 Inventory: every ordered part has arrived
    All 33 ordered/shipped rows marked received after a physical inventory
    on 2026-09-26, including the RobotShop shipment (Pixhawk, Pololu,
    servo tester, Bar30) and the calipers. Nothing is blocking Phase 1/2
    bench acceptance any more.
    Differences from the order, recorded on their rows:
    - Anker power bank was a 2-pack; qty 1 -> 2.
    - BOJACK fuses: 4 arrived against a listing of 3.
    - XT60 pigtails: two packs of 6; pieces vs pairs still to confirm,
    which decides whether the 6 ESC drops have any spares.
    - Cable glands arrived in a package marked E271; PG7/PG9 count unchecked.
    - Tomotato dry box is too small for the Opal + power bank and needs
    replacing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
2026-09-26 Dome flange measured: stereo baseline moves from 75 to 74 mm
    The SupremeTech flange is 71.9, not the ~70 the housing layout assumed,
    and the layout said to re-examine the baseline if that happened. At 75
    the bore clearance fell to 3.6 (rule: >= 4) and the flange gap to 3.1
    (rule: >= 5); no baseline met both.
    The bolt pattern breaks the tie. Six holes on a 64.5 circle (~2.0 holes,
    M2 class) sit 3.7 mm inside the flange edge, so facing bolts are 9.5 mm
    apart at 74 even when aligned, ~18 mm clocked +/-30 deg. The >= 5 gap
    rule existed only for bolt clocking; it becomes >= 2 (no contact, with
    placement tolerance). 74 gives 4.1 bore clearance and 2.1 gap and stays
    in the 60-120 band. 73 was reje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
2026-09-26 Add Pi 5 mechanical drawing as CAD reference
    Raspberry Pi's official RP-008347-DS-1 drawing: board outline,
    mounting holes, connector positions. Used for the Pi 5 bench holder
    (first print, 2026-08-30) and needed again for the in-hull Pi mount
    and the stereo camera fixture.
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2026-09-26 carp_camera: both cameras to H.264 rosbag, 720p10 defaults
    ros/carp_camera launches one component container holding, per camera, a
    camera_ros node (picked by its stable device-tree id) and an
    image_transport republisher that encodes raw bgr8 to H.264
    (libx264 ultrafast/zerolatency, keyframes every 1.5 s) as
    ffmpeg_image_transport FFMPEGPacket. Intra-process comms keep the raw
    frames out of DDS. record:=true adds an MCAP rosbag of the packets and
    camera_info.
    Defaults are 1280x720 at 10 fps: the most the uncooled Pi 5 sustains
    with headroom (~20% CPU, 65 C). 1080p30 saturated the CPU at ~10 fps
    per camera and throttled at 85 C.
    Workspace scripts use rosdep from package.xml, skipping the lib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
2026-09-26 Encode results in ADR-015/017; drop Foxglove, which was never chosen
    Foxglove came in with the first agent-written docs as if it were a
    requirement; it wasn't. Recording format is FFMPEGPacket, matching
    unh_marine_perception so the same decode and rqt tools work; playback is
    checked by decoding, not by a named viewer.
    ADR-015 gets the measured table: 1080p30 stereo does not fit on the
    uncooled Pi 5 CPU (~10 fps per camera, throttling at 85 C); 720p10 keeps
    every frame at ~20% CPU and 65 C. ADR-017's bench gate is met at 720p10
    on Ubuntu, so B1 holds; stereo sync is the open problem (free-running
    cameras, 49 ms apart this run; no documented hardware trigger for the
    IMX462 Pivariety; Raspberr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
2026-09-27 ADR-017: state the sync offset in sensor lines correctly
    23 us is ~1.5 lines at 14.8 us/line, not under one line.
2026-09-27 Pixhawk flashed: ArduSub 4.7.1, accel calibrated, first param snapshot
    Pixhawk1-1M Sub/stable 4.7.1 (git dbe79216) loaded as a custom
    firmware file from QGC 5.1.4 on Windows. Boots to MANUAL; attitude and
    compass respond. Onboard sensors: IST8310 compass (I2C0), MS5611 baro
    (SPI1).
    params/carp-bench-2026-09-26.params is the post-accel-cal snapshot.
    Offsets X 0.01 / Y -0.30 / Z 1.26 m/s^2, scales within 0.5%. Only one
    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
    [carp-bench-2026-09-26.params]
2026-09-27 Pixhawk has 2 MB flash: reflashed to full Pixhawk1 build; IMU and SD pass
    The Pixhawk1-1M build logged "2M flash - use Pixhawk1 firmware" on every
    boot, so ADR-008's 1 MB ceiling does not apply to this Radiolink unit.
    Reflashed to the full Pixhawk1 build (same ArduSub 4.7.1, dbe79216);
    calibration and parameters carried over. It adds 91 parameters: Lua
    (SCR_ENABLE), mount/gimbal, IMU temperature cal, a third harmonic notch,
    more filters. No DDS_* parameters, so AP_DDS is still out and ROS 2 over
    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
    [carp-bench-2026-09-26.params]
2026-09-27 Bar30 plug does not fit the Pixhawk I2C port: DF13 vs JST-GH confirmed
    The Bar30 ships with a JST-GH lead; this Pixhawk's I2C port is DF13, as
    the pigtail row warned. That blocks the Phase 1 depth check until a
    4-pin DF13-to-JST-GH adapter (or a DF13 pigtail to splice) is in hand.
    The row now says to match wires by function, not position, and to check
    both pinouts before powering. Do not cut the Bar30's potted lead.
2026-09-27 camera_ros: fix shutdown hang from a lost condition-variable wakeup
    Stopping the pipeline hung ~1 in 3 times until launch SIGKILLed the
    container. gdb showed the main thread in ~CameraNode -> std::thread::join
    on a request thread asleep in pthread_cond_wait inside
    CameraNode::process: the destructor set running=false and notified
    without the request mutex, so a thread busy with a frame missed the
    wakeup, went back to wait() with no predicate, and never woke (the
    completion callback was already disconnected).
    patches/camera_ros/0001 (applied by setup-ros-workspace.sh) waits on a
    per-request ready flag set by requestComplete, and notifies under each
    request's mutex on shutdown and disconnect.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
2026-09-27 Orders: Bar30 adapter + SOS leak sensor (Blue Robotics), 500 mm FFC set
    Blue Robotics, $54.94 incl. shipping and a $1.44 tariff surcharge:
    - JST-GH to DF13 adapter board, 4-pin ($13.44). Unblocks the Phase 1
    Bar30 check with the pinout guaranteed; the pigtail row shrinks to
    "DF13 pigtails only if another port needs one".
    - SOS Leak Sensor ($35) replaces the bare-wire probe: four sponge probes
    that need liquid rather than condensate, 3-pin out to a Pixhawk AUX
    pin, ArduSub-native. Needs 3.3-5 V on the servo rail (one ESC BEC,
    still unconfirmed, or a separate 5 V feed).
    uxcell 22-pin 0.5 mm Type B FFC, 500 mm x5 ($6.47): bench, mock-up and
    fixture cables. The vehicle-length row now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
2026-09-27 Orders: Pi 5 Active Cooler, 27 W bench supply, bench power strip
    Amazon, 2026-09-27, $33.93:
    - Official Pi 5 Active Cooler ($10.95, third-party seller at ~2x list;
    check it is genuine). Every ADR-015 bench number was uncooled; re-run
    them with it. It moves SoC heat into the hull air, not out of the hull,
    so it pairs with an air-stirring fan or a conduction path.
    - iRasptek 27 W 5.1 V / 5 A USB-C PD supply ($10.99), bench only: fixes
    the undervoltage the Pi hit on a 4.9 V supply (ADR-017).
    - Surge-protected power strip ($11.99) under shop tooling.
    Totals: paid $1,782.33, projection ~$2,155-2,260; shop tooling $407.32
    out of pocket ($483.37 list).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
2026-09-27 cad/README.md: Onshape plan for the stereo camera carrier
    Working plan for turning sled.md and housing-layout.md into a printable
    stage-1 carrier: measurements to take first (with a fill-in table for
    the dome and the B0444 board), the Onshape document layout (Variable
    Studio with the driving variables, one multi-part Front part studio off
    a single layout sketch), build order, printing notes (tolerance coupon,
    seats face-down, PLA+ for bench), hardware still to buy, and the air
    calibration check. Meant to be trimmed as steps get done.
    Claude-Session: https://claude.ai/code/session_01A6qKmysmmcRm6a4cCxdTar
2026-09-27 cad/README.md: image orientation checks
    Bench tests ran with the boards cables-up and the images looked upright,
    but nothing in the repo rotates or flips, so either the sensor is upright
    that way, libcamera compensated for an overlay rotation using the sensor
    flip bits, or the preview step flipped it. Adds the three checks on the
    Pi (device-tree rotation, sensor flip controls while streaming, a frame
    straight from the bag), how to read them, and what it means for the
    carrier: mount both boards alike, choose for ribbon routing, match in
    software, calibrate with the final settings.
    Claude-Session: https://claude.ai/code/session_01A6qKmys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
2026-09-27 Dome and B0444 measurements: board sits inside the lid, stepped hole
    Calipers, 2026-09-27. The 2" dome is a hemisphere (H 26.7, OD 52.4,
    R 26.3 by sagitta) with its centre ~0.4 in front of the flange back
    face, i.e. on the lid's outer face. The flange is 2.0 thick; the listed
    "3/8"" is its radial width. The lens front stands 17.0 above the board,
    so on the 19 mm acrylic lid the board sits inside the lid thickness.
    The lid's camera hole becomes stepped: Ø16-18 through for the Ø14
    barrel, Ø52 counterbore from the inside ~8 deep for board, connector
    and a tightly bent ribbon (8 mm reach). The flange face stays whole for
    the dome seal.
    B0444 checked against the STEP: 25.1 x 24.4 x 1.7, hole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
2026-09-27 Answer image orientation and sensor row direction from the Pi
    Overlay rotation is 0 and the sensor flip bits read 0 on both cameras
    while streaming (camera_ros orientation 0), and the 2026-09-26 frames were
    decoded without any flip, so cables-up is the sensor's natural upright.
    Pixel rows run along the 25 mm side, parallel to the connector edge
    (inferred from those frames and the measured board geometry; a "TOP"
    sheet shot would confirm).
2026-09-27 sled: leave the lens entrance pupil to the stage-2 wet tune
    Start from the pupil ~3 mm behind the front element; the spacer range and
    counterbore margin absorb the error, and the through-hole keeps its chamfer.
2026-09-27 cad: Onshape notes for agents, Pi holder STL, next bench print
    onshape-notes.md, researched 2026-09-27 so later sessions needn't redo
    it: what an agent can and can't do (no GUI; guide, analyse exports
    locally with a trimesh recipe, the official FeatureScript MCP server in
    Onshape Labs, or the REST API), plan terms, the 2,500 calls/user/year
    API quota on Free/Standard, API V17 and export endpoints, the 2026
    changes that matter here (configurations, Variable Studio in
    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
    [pi_bracket.stl]
2026-09-27 Screwless camera seats; snake_case variable names; Pi 5 STEP source
    Camera boards mount screwless (sled.md, "Holding each board"): 1.75 mm
    filament pins through the board holes locate, one PETG retainer snapped
    over both boards clamps against lift and ribbon pull. Heat-staking is the
    alternative, M2 screws + inserts the fallback. The tolerance coupon now
    tests 1.75/1.8/1.85 pin holes and a snap-fit; no hardware to buy for the
    board seats.
    Variable naming conventions settled before the Onshape Variable Studio
    exists (cad/README.md): snake_case, whole words, subject first, a fixed
    set of property words, derived values as expressions, units and source
    always, shared vs local, fits as their own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
2026-09-27 Board seats: print-only, method open; variable table synced to Onshape
    sled.md and cad/README.md walked back "filament pins, decided": the seat
    method is open and print-only. Candidates: slide-in rails with a detent,
    printed pins or a pocket plus a snap-on retainer, a retainer held by a
    printed thumb-nut, split snap pins (likely too fragile at 2.0 mm holes in
    FDM), filament pins set aside. For the bench rig stability matters more
    than absolute position; the 0.2 mm target applies to the vehicle
    carrier. The tolerance coupon tests rail grooves, printed pins, a PETG
    latch and a printed nut, and picks the method.
    Variable table matches the Housing Variable Studio as created: adds
    camera_board_t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
2026-09-28 Vehicle frame: Y to port (right-handed); origin at the front pipe end
    Frame: X forward, Y to port, Z up (ROS REP-103), what Onshape builds in.
    housing-layout.md had port at -Y with Z up, a left-handed frame that
    would have modelled mirrored; thrusters 1-4 flip Y sign. ArduPilot's
    forward-right-down frame in frame-and-mixing.md is separate and
    unaffected.
    Origin: the front pipe end on the tube axis (the front lid's inner face)
    instead of the tube's mid-length, as a ship draws from its aft
    perpendicular and baseline: a physical datum fixed early that everything
    mates to. Lid-material changes then move only the lid face, domes and
    cameras together; tube-length changes only the rear. X position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
2026-09-29 cad: tolerance coupons A and B, first rail and pin results
    Coupon A (PLA+): three rail pairs with grooves at board thickness +0.1 /
    +0.2 / +0.3, and three pin pads at 1.80 / 1.85 / 1.90 on a diagonal of
    the B0444 hole pattern. Coupon B (PETG): cantilever latches with 1.0 and
    1.4 arms plus a catch, and three M6 x 1.0 stud and nut pairs using
    Plastic Thread's Close / Normal / Loose presets. README section 4 now
    holds the spec and a results table instead of a one-line coupon plan,
    and notes that rails and pins can't print seat-face down.
    First results from A: +0.1 rails a bit tight, +0.2 a bit loose, so
    about +0.15; all pins too small, the board moves around. B is still
    printing.
    onshape-note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
    [coupon_a_c1.stl, coupon_b1.stl]
2026-10-03 Board seats: slide-in rails at +0.1; coupon B results
    Coupon results: rail grooves at board thickness +0.1 work well once
    broken in by a few insertions, so rails are the chosen print-only seat
    method (moved to the decided list). Printed pins come out ~0.05 under
    design. Coupon B latches snap in but hold weakly (1.0 arm weaker than
    1.4); all three M6 nut presets thread smoothly and hold when snug, with
    Close wobbling least.
    Open: what holds the board at the rails' open end, a printed detent or
    a nut-held retainer that also clamps behind the connector. The carrier
    now prints seat-side up, since rails stand up from the seat face.
2026-10-03 bom: leak sensor, JST adapter, camera cables, cooler, PSU, strip received
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2026-10-11 First stereo bracket print: 95 mm baseline tested, not decided
    Bracket and sled part sliced 2026-10-10 in PETG (0.16 mm, 2 walls, 15%
    infill, 23.3 g). Cameras fit the slide-in rails well. The bracket is
    flimsy: ~2 mm base plate over a 124 mm span. One camera ribbon is tighter
    than Roland likes, so the Pi will probably move closer to the cameras.
    The bracket was printed at 95, read from the exported STL. stereo_baseline
    stays an open choice, and the variable table row still says 74 until it is
    checked against Onshape.
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2026-10-11 acoustic: bench tools for the ranging tests
    Standalone Python (apt packages only, no ROS) for the acoustic ranging
    work in docs/navigation.md:
    - ranging_dsp, pinger: chirps, matched filter, first arrivals, and ping
    designs made of named signals fired on chosen output channels at chosen
    times. Warns when events cannot be told apart or leak into each other.
    - ping_gui: window to edit signals and designs, ping once or continuously,
    and see arrivals; plus a stepped-chirp frequency sweep, a background
    noise measurement and a LoRa-style chirp data link.
    - loopback_test, plot_runs: command-line ping and plots of saved runs.
    - chirp_data: chirp spread spectrum modem with a preamble and CRC-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
2026-10-12 acoustics_lab: user-experience decisions, scenes and the bench as built
    Page list on the left; model and experiment on the same page; notes as a
    collapsible panel of short text with live values (after Ciechanowski,
    Tangle, PhET and the Sensor Array Analyzer); air and water numbers both
    shown by default, configurable per workspace. One active scene for the
    whole tool, with pages declaring what they need and offering scenes that
    fit. Scene and rig are chosen separately, so unbuilt setups can be
    simulated, but each rig has an as-built twin scene, an "As built" button
    returns to it, and the toolbar says when a simulated scene is not the
    bench.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
2026-10-12 acoustics_lab: duplex device stream with scheduler, input ring and xrun log
    One PortAudio callback stream per device through ctypes (a dongle is stereo
    out, mono in), plus a fake device with a loopback, latency, drift and
    injected xruns behind the same interface.
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2026-10-12 acoustics_lab: duplex_check borrows the card, checks the built-in speakers and capture source
    The card is borrowed before PortAudio looks at it and given back on exit,
    errors and Ctrl-C. The built-in card's speaker switch and Capture Source
    are read after borrowing, with the command to mute the speakers. Docs
    describe the protocol, the crash safety and how to check by hand.
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2026-10-25 bom: 382213 outputs are one adjustable, fixed 12 V and fixed 5 V
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2026-10-25 bom: EX430 mA fuse likely blown
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2026-10-25 bom: 382213 current limit and fixed outputs check out; EX430 temperature probe works
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2026-10-25 acoustic: TRRS terminal cable buzzed out; labels assume OMTP
2026-10-25 acoustic: dongle is CTIA, mic bias 3.72 V on the sleeve; cable labels V/Grd swapped
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2026-10-30 docs: topside acoustic head written up as a post-1.0 idea; array pattern script
    docs/topside-head.md: one PoE head for multibeam imaging, ROV tracking and
    acoustic comms, built from the tracking cross filled into a 32-channel
    cored Mills cross. Status idea, Roland's, nothing decided. Its §2 lists
    what Tracking 1.0 should fix so the ROV's 2x2 on a UCA222 stays
    compatible. Beam patterns and costs are agent estimates.
    acoustic/array_patterns.py reproduces every beamwidth and leakage figure
    in the document (ideal array factors, numpy only).
    Pointers from README, navigation.md Method 4, bom.md Options and the
    acoustic README.
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2026-11-02 U2 plug cut, pinout proven, first thruster spins; servo tester checked
    Thruster on the bench supply at 12 V: arms, 0.02 A idle, dead zone
    1460-1505 us. Pins 1 GND black, 2 signal yellow, 3 V+ red. SP13 mates do
    not fit, so the plugs get cut. Servo tester pinout and pulse widths
    confirmed on the scope. Fuse block ordered, BOM totals reconciled.
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2026-11-07 cad: block LEDs between the fuses; both covers pull off, no swing clearance
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2026-11-08 cad: fuse block drawing linked; screw row orientation corrected to assumed along the length
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2026-11-08 cad: MIDI holder and block rows follow the Onshape models, which corrected the caliper readings
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
